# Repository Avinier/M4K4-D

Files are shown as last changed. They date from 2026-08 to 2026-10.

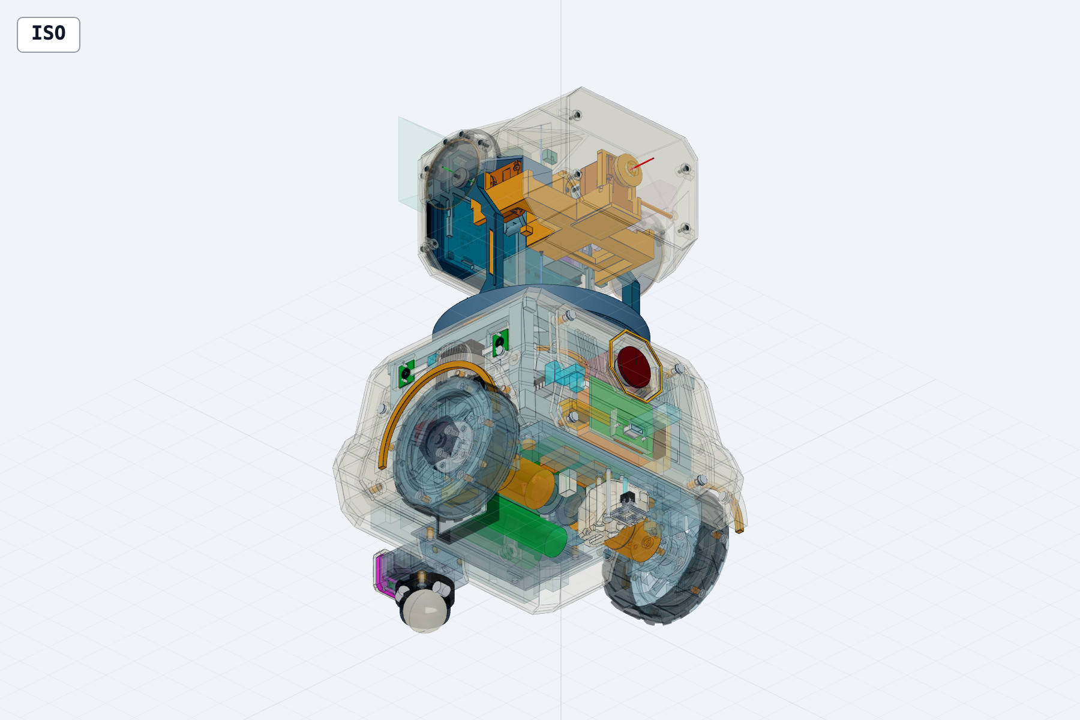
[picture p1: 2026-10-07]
docs/03-build/03-head/v1/cad/snapshots/head-v1-integrated-ear-opposite_20261005T164502Z.png

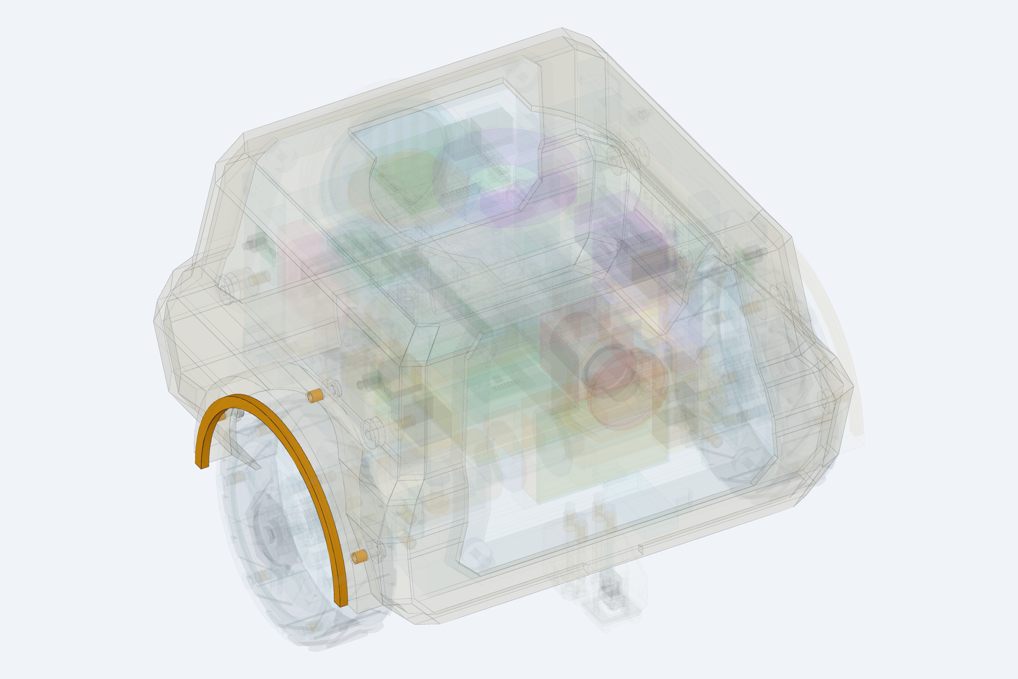
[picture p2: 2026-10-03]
docs/03-build/02-body/v1/cad/snapshots/body-v1-wheel-arch-joint-inside-2026-10-03.png

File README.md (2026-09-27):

# Makad / M4K4-D

> **Current project overview** — last reconciled **26 September 2026**
>
> Foundation approved: **14 August 2026** · V1 deadline: **5 December 2026**

**Makad**, technical designation **M4K4-D** and commonly shortened to **M4**, is a personal droid. M4 is intended to occupy the kind of companion role R2-D2 occupied for Luke Skywalker: recognizable, attentive, expressive, and full of character.

The central V1 priority is simple:

> **M4 should feel alive.**

Makad's defining advantage is expressiveness. That expression comes from what M4 understands, sees, and hears, and from how convincingly its display, status light, astromech audio, head, wheeled base, and timing communicate one intent.

`00-foundation` is the product-intent authority. Documents under `01-system` and `02-prototypes` are engineering reference. Design, sourcing, CAD, software, and hardware proceed together.

This README orients the repository around the current design, current build state, and immediate next work. [`MEMORY.md`](MEMORY.md) is a short chronological log of later consequential discoveries and decisions.

## Current design

M4 is a battery-powered floor droid with a three-axis head, an animated face, a camera-side status light, body-mounted hearing and speech, and a two-wheel base. The head carries the display, camera, status light, C2 motion controller, and local structure. The body carries four PDM microphones, the speaker, battery, and main compute. Floor mode is primary; tabletop mode inhibits locomotion by default.

The current physical target is **300 × 205 × 180 mm**. Head Layout 04 and body/chassis Layout 02 give a **293.5 mm** neutral stack (140 mm body-top datum + 49.5 mm neck + 104 mm crown-inclusive head). Drive geometry is Ø84 mm wheels, 170 mm track, 110 mm axle-to-front-support, and a mandatory rear anti-tip skid. Front support is a Ø1″ ball transfer; a swivel caster remains a comparison article on a rig, while the present CAD mount is ball-only.

Working geometry lives in [`docs/02-prototypes/RP-06-cad/`](docs/02-prototypes/RP-06-cad/README.md): head [Layout 04](docs/02-prototypes/RP-06-cad/head/layout-04/README.md) and body/chassis [Layout 02](docs/02-prototypes/RP-06-cad/body-chassis/layout-02/README.md).

### Selected components

| Item | Selection | Record |
|---|---|---|
| Face display | Waveshare ESP32-S3-LCD-4.3, **no-touch, SKU 30493** — 800×480 IPS with on-board ESP32-S3/LVGL renderer | [`display-candidate-study.md`](docs/01-system/display-candidate-study.md) |
| Head camera | Raspberry Pi Camera Module 3 **Wide**, visible-light, **SC0874** | [`camera-candidate-study.md`](docs/01-system/camera-candidate-study.md) |
| Head motion controller (C2) | Waveshare **ESP32-S3-Zero**, headerless; bench twin ESP32-S3-DevKitC-1-N8R8 | [`control-topology-options.md`](docs/01-system/control-topology-options.md) §6.3 |
| Main compute (C0) | **Raspberry Pi 5, 2 GB** with official Pi 5 Active Cooler; storage and power-entry implementation still open | [`compute-control architecture`](docs/02-prototypes/RP-02-electrical/compute-control-architecture.md) |
| Base controller (C3 prototype) | **Espressif ESP32-S3-DevKitC-1-N8**, selected over N8R8 to preserve GPIO35–37 | same, CA-03 |
| Control split | C0 owns semantic behaviour; D1 renders eyes; C2 owns head trajectory and local safety; C3 owns base loops and local hazards. Production links are differential UART; C2 relays face/light state locally | same |
| Drive topology | Two encoder wheels + **front ball transfer** + mandatory rear anti-tip skid | [`dimensional-baseline.md`](docs/01-system/dimensional-baseline.md) v1.12 |
| Head construction | PLA structure and skin (provisional beyond first head), real M2 button-heads, nine-step weathered finish | [`material-finish-mass-decision.md`](docs/02-prototypes/RP-01-head/material-finish-mass-decision.md) |
| Head layout | Serial body→yaw→pitch→roll; coaxial direct roll on a supported spindle; ears roll with the face; trapezoidal camera crown; external yaw cable loop; C2 on the rolling cradle; A0 balance target | [`head/decisions.md`](docs/02-prototypes/RP-06-cad/head/decisions.md) |

Working choices now cover XC330-M181-T yaw and XC330-M288-T pitch/roll at 5 V, a two-cell Samsung 25R pack with custom protection, Pololu #4804 as the preferred drive-motor candidate, the audio and status-light parts, and the four-board power architecture. These are not purchased or bench-frozen. Motor SKU lock, production camera interconnect, moving harness, storage, board schematics and layouts, and power/safety proof remain open.

## Current build state

The design is far ahead of the physical robot. Head and body CAD exist; electrical and locomotion behaviour are specified on paper; no integrated article has been built, weighed, or run.

| Area | State (2026-09-26) |
|---|---|
| Foundation | Approved. Some numeric thresholds remain open. |
| Geometry | Head Layout 04 is the working 1:1 model; body/chassis Layout 02 live-imports it. Neutral height is 293.5 mm. Screw collisions and sign mapping are closed in CAD; stiffness, hard-stop impact, bearing fit and balance trim await hardware. The body layout still has unresolved connector, joint and safety details. Not a fabrication release. |
| Head mechanism | Concept A (elevated-ear serial gimbal) is the path. The XC330 family is a working choice, with internal inertia bounded on paper. Nothing is weighed; actuator B1–B6 tests remain. |
| Electrical / control | States, power topology, compute split, and C0↔C2 message/recovery design are written. Host codec work is exploratory. Pack sizing still needs drive measurements. |
| Locomotion | Two-wheel + ball + skid is the V1 type. Pololu #4804 is the preferred motor candidate and its official STEP is in CAD; SKU lock, hubs, axle proof and drive tests remain. Layout 02 packages one guarded rear TCRT channel, short of the fuller stop-path sensing in the control design. |
| Interaction / following | Audio-path requirements and following architecture are documented. No SKU, corpus, or physical test. |
| Software / firmware | Timebase, link contract, C2/C3 firmware, and C0 behaviour are specified more than implemented. |
| Physical hardware | Selected display, camera, C2, Pi 5, and cooler are locked on paper. First weigh-ins wait on samples. No head, chassis, or electrical rig has been built. |

`visuals/` are provisional references; several show superseded details (mouths, ear microphones, yoke-mounted ears).

## Immediate next work

Sourcing, CAD, software, and hardware proceed together. The useful next work is:

- **Verify the current head design on hardware:** measure pitch/roll stiffness, hard-stop impact and balance trim; trial-fit the 696-2Z bearings and XC330 actuators.
- **Choose and source remaining parts** as packaging needs them — head servos, wheels/hubs/motors, ball transfer, battery and power hardware, audio, status LED, connectors — and replace CAD envelopes with real geometry.
- **Keep the whole-robot model current** in RP-06: the 293.5 mm stack is closed in CAD; reconcile Layout 02's rear-only cliff channel and low-object contact gap with the base safety design.
- **Implement firmware and software** on the same timeline: C2/C3, C0 behaviour and perception, the serial link and timebase, and face rendering on the display.
- **Build and measure** as parts arrive: weigh display, camera, C2, prints, and finish coupons; print the head and chassis; stand up a protected bench and start moving hardware.

## Documents

### Product intent — authoritative

- [Vision](docs/00-foundation/vision.md)
- [V1 scope](docs/00-foundation/v1-scope.md)
- [Constraints](docs/00-foundation/constraints.md)
- [Success criteria](docs/00-foundation/success-criteria.md)
- [Core interaction scenarios](docs/00-foundation/core-interaction-scenarios.md)

### Current engineering

- [Dimensional and packaging baseline](docs/01-system/dimensional-baseline.md)
- Working CAD: [RP-06-cad](docs/02-prototypes/RP-06-cad/README.md) — [head Layout 04](docs/02-prototypes/RP-06-cad/head/layout-04/README.md), [body/chassis Layout 02](docs/02-prototypes/RP-06-cad/body-chassis/layout-02/README.md)
- Ledgers: [mass/envelope](docs/01-system/mass-envelope-ledger.md), [power/energy/thermal](docs/01-system/power-energy-ledger.md), [candidate sourcing](docs/01-system/candidate-sourcing-matrix.md)
- Studies: [control topology](docs/01-system/control-topology-options.md), [display](docs/01-system/display-candidate-study.md), [camera](docs/01-system/camera-candidate-study.md), [head harness](docs/01-system/head-harness-routing-study.md)

### Research and history

These folders are engineering reference. They do not set how work proceeds.

- [System design brief](docs/01-system/system-design-brief.md), [risk-prototype plan](docs/01-system/risk-prototype-plan.md), [workbench](docs/01-system/workbench.md), [run-record convention](docs/01-system/run-record-convention.md)
- Head: [`RP-01-head/`](docs/02-prototypes/RP-01-head/)
- Electrical: [`RP-02-electrical/`](docs/02-prototypes/RP-02-electrical/README.md)
- Locomotion: [`RP-03-locomotion/`](docs/02-prototypes/RP-03-locomotion/README.md)
- Coordination: [`RP-04-coordination/`](docs/02-prototypes/RP-04-coordination/README.md)
- Interaction: [`RP-05-interaction/`](docs/02-prototypes/RP-05-interaction/README.md)
- Following: [`RP-07-following/`](docs/02-prototypes/RP-07-following/README.md)
- Earlier memory log: [`archive/MEMORY-20260921.md`](archive/MEMORY-20260921.md)

## Repository

```
docs/00-foundation/     product intent and constraints     authoritative
docs/01-system/         engineering reference
docs/02-prototypes/     studies, calculations, and working CAD
docs/archive/           superseded documents
archive/                prior process log
MEMORY.md               chronological build and decision log
README.md               this orientation
```

## Identity and design direction

M4 is a droid, not a desktop assistant, smart speaker, or generic social robot. The approved direction is:

- strongly inspired by Star Wars droids;
- cyberpunk, rugged, scrappy, and characterful;
- mechanical rather than glossy or appliance-like;
- modular and screw-together, with visible fasteners, panels, seams, and service access as part of the personality;
- eyes only on the face, no mouth;
- approachable without optimizing for minimum size;
- open to substantial redesign from the current renders.

## V1 Core

V1 is not complete unless the following outcomes work together as one droid. Exact wording lives in [`v1-scope.md`](docs/00-foundation/v1-scope.md) (SCOPE-01…21).

**Expression and character** — animated face on the onboard display; powered roll, pitch and yaw head motion; at least one controllable LED beside the camera; a builder-authored non-English astromech language; idle aliveness without manual control; display, LED, audio, head, base and timing express one intent; at least one bounded excited spin.

**Understanding and perception** — natural spoken interaction within the approved scenarios; invocation forms **"M4," "M4K4," and "Makad"**; visual acquisition of a nearby person or face; tracking maintained or reacquired through later-defined test cases.

**Mobility and following** — battery-powered wheeled floor droid; "come here" finds, approaches and stops at a bounded distance; "follow me" tracks the selected person through an approved indoor route; obstacles, stopping, target loss and unsafe conditions are handled without continuing blindly.

**Utility and entertainment** — display the time; create and signal timers and alarms; start Spotify playback through an approved integration; eyes "vibe" to music.

**Operation and construction** — untethered on onboard battery for at least 20 minutes; floor mode primary; tabletop mode inhibits locomotion by default and protects edges; accessible stop or cutoff with bounded failure; assembled, started, demonstrated, inspected and serviced from documentation.

**Candidate:** spatial/directional hearing, included only if it materially improves an approved interaction. Everything else is uncommitted; there is no permanent "never" list.

## Approved Core scenarios

Source: [`core-interaction-scenarios.md`](docs/00-foundation/core-interaction-scenarios.md).

**1. Wake, socialize, assist.** M4 idles head-down. A person calls its name. M4 wakes as one coordinated performance: three-axis head rise, eyes, camera-side LED, astromech acknowledgement, face acquisition and gaze. A greeting produces an in-character response. The person can request the time, a timer, an alarm, or Spotify playback; M4 confirms visibly, performs it, and vibes during music.

**2. Come here and follow me.** On an approved floor, the person invokes M4 and says "come here." M4 acknowledges, searches, acquires, turns, approaches safely and stops approximately 0.6–0.9 m away. "Follow me" makes M4 follow through an approved route of up to about 3 m at no more than about 0.5 m/s while handling obstacles and target loss. When continuing is unsafe, M4 stops and says so. M4 performs an excited spin and settles.

## Success definition

V1 succeeds when M4 delivers these interactions as a convincing, repeatable droid encounter on battery power, not as a sequence of manually rescued subsystem demos. The validation categories and open thresholds are in [`success-criteria.md`](docs/00-foundation/success-criteria.md) (SC-01…25).

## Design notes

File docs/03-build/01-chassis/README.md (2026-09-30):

# 01 — Chassis and locomotion

The [v1 BOM](v1/BOM.md) lists installed chassis quantities, references to full-system electrical parts and the separate bench-test requirements, and the open decisions that prevent release. The [project BOM](../BOM.csv) is the canonical register for sourcing and status. The [v1 CAD starting point](v1/cad/README.md) defines the current model boundary and exclusions. The [v1 test system](v1/testsystem.md) sets out receiving checks, coupons, fixtures, assembly and stress tests, and the rolling-chassis test sequence.

The v1 snapshot is a working list. Freeze it only after purchased parts are received and measured, custom parts and fasteners are specified, and the chassis checks and test criteria are complete.

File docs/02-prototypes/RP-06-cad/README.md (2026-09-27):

# RP-06 — Sourced layout CAD

| Field | Value |
|---|---|
| Status | **This folder owns the working CAD.** Phase A packaging is the article. Physical validation is 0%. No gate registered, no mock-up built, no scored run |
| Governing plan | [`risk-prototype-plan.md`](../../01-system/risk-prototype-plan.md) v1.15 §RP-06 |
| Purpose | Working whole-robot packaging for an obtainable, serviceable layout |
| Active models | Head [Layout 04](head/layout-04/README.md). Whole body [Layout 02](body-chassis/layout-02/README.md) |
| Closure instrument | [`TODO.md`](TODO.md); detail in [`checklist.md`](checklist.md) |

RP-01 is an object. RP-02 is states and interfaces. RP-03 is a vehicle plus local safety. **RP-06 is the whole-robot packaging prototype**, and therefore the home of the CAD.

RP-01 and RP-03 keep mechanism, physics, gates and rigs; they link here for geometry.

## Start here

| Document | What it owns |
|---|---|
| [TODO](TODO.md) | Builder remaining-work punch list |
| [Closure checklist](checklist.md) | Remaining G01–G06 work; CAD-done vs physical-open |
| [Head Layout 04](head/layout-04/README.md) | Active 1:1 head. Viewer, verification, mass tree |
| [Body/chassis Layout 02](body-chassis/layout-02/README.md) | Active whole-robot assembly. Live-imports Layout 04 |
| [Head decisions](head/decisions.md) | Head CAD decisions and revisions |
| [Body/chassis CAD-context decisions](decisions.md) | `RP03-CAD-01…12` (CAD-first, not RP-03 safety approval) |
| [Peripheral selection](peripheral-selection.md) | Audio path, mics, speaker/amp, status LED and base IMU working selections (2026-09-26) with evidence |
| [Prototype open items](../openitems.md) | Folder-wide remaining-open index |

## CAD map

```text
RP-06-cad/
├── head/                  Layout 04 active; 03, 02 and 01 preserved
│   ├── layout-04/         1:1 packaging, service, optics, harness overlays
│   ├── layout-02/         preserved previous head
│   ├── layout-01/         first study + purchased catalog STEP
│   ├── decisions.md
│   └── requirements.md
├── body-chassis/
│   ├── layout-02/         active whole-robot model
│   └── layout-01/         previous body; shared purchased/ STEP
├── decisions.md           body CAD-context register
├── TODO.md
└── checklist.md
```

Open Layout 04 in CAD Viewer from [`head/layout-04/README.md`](head/layout-04/README.md). Open the whole robot from [`body-chassis/layout-02/README.md`](body-chassis/layout-02/README.md). Body/chassis composes the head from live Python source — do not redraw it as an AABB.

| Head notes | Body notes |
|---|---|
| [Layout 03 brief](head/layout-03-brief.md) | [Layout 02 brief](body-chassis/layout-02/brief.md) |
| [Layout 03 verification](head/layout-03/review/verification.md) | |
| [Packaging estimates](head/packaging-estimates.md) | [Layout 01 body](body-chassis/layout-01/README.md) (preserved) |
| [Pre-layout brief](head/pre-layout-brief.md) | Purchased Pi 5 / 608ZZ STEP live locally under `body-chassis/layout-01/references/purchased/` (not in Git) |

## Locked inputs RP-06 may not reopen

| Item | Value | Home |
|---|---|---|
| Moving-head load | Layout 04's current hand-kept mass tree is about **588 g**; it is an estimate, not M900 `W`. Layout 03's 499–524 g screening range is historical. Former ~250 g target is inadmissible | [Layout 04](head/layout-04/README.md); [`dimensional-baseline.md`](../../01-system/dimensional-baseline.md) |
| Head envelope | **104 × 150 × 115 mm** crown-inclusive | same |
| Neutral stack | **293.5 mm** (140 body + 49.5 neck + 104 head, head Layout 04 turntable). Meets the 300 mm rounded target with 6.5 mm to spare; closed 2026-09-26 | same |
| Display / camera / C2 / C0 | SKU 30493; SC0874; ESP32-S3-Zero; Pi 5 2 GB + official Active Cooler | component studies; RP-02 |
| Drive topology | Two-wheel + Ø1″ ball + rear skid | baseline v1.12 |

## Owned elsewhere — link, do not copy

| Subject | Home |
|---|---|
| Dimensional / CoM targets | [`dimensional-baseline.md`](../../01-system/dimensional-baseline.md) |
| Mass ledger | [`mass-envelope-ledger.md`](../../01-system/mass-envelope-ledger.md); RP-01 [`payload-mass-capture.md`](../RP-01-head/payload-mass-capture.md) |
| Sourcing / landed cost | [`candidate-sourcing-matrix.md`](../../01-system/candidate-sourcing-matrix.md) |
| Display / camera / harness gates | display study; camera study; [`head-harness-routing-study.md`](../../01-system/head-harness-routing-study.md) |
| Head motion / actuators / scored gates | RP-01 `physics.md`, `gates.md`, `rig.md` |
| Drive physics / scored gates | RP-03 `physics.md`, `gates.md`, `rig.md` |
| Audio `AR-*` / `AP-*` | RP-05 [`audio-requirements.md`](../RP-05-interaction/audio-requirements.md) |
| Thermal trip-wire T-3 | [`power-energy-ledger.md`](../../01-system/power-energy-ledger.md) |

## What to do next

1. Keep editing **this** tree. Fit actual sourced articles into body Layout 02 and head Layout 04.
2. ~~Accept or recover the 304 mm stack~~ — closed: the neck is 49.5 mm, the stack 293.5 mm. **CoM:** [`RP03-CAD-09`](decisions.md) accepted a previous 2,568 g hand-kept register at x +18.77 / h 105.05 mm, retaining the 81.6 g [`RP03-CAD-08`](decisions.md#rp03-cad-08--ballast-bar-ahead-of-the-battery-tub) bar and adding no more. The latest `body-chassis/layout-02/generated/mass-properties.md` reads 2,551.9 g at x +19.46 / h 107.27 mm (a_tip 1.78 m/s²); the physical robot still needs weighing.
3. Do not ballast the head to 250 g.
4. Physical mock-up and G01–G06 registration wait on representative head, electrical, and acoustic evidence.

## Organization record — 2026-09-21

Builder direction: all prototype CAD from RP-01 and RP-03 moves here as `RP-06-cad`. RP-01 `cad/` and RP-03 `cad/` become forwarding stubs.

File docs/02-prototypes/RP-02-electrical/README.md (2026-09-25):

# RP-02 — Electrical/Control Backbone

| Field | Value |
|---|---|
| Status | **Parts 1–4 are complete at design-definition level.** Part 4 is `RP02-P4-REG-01` (C0↔C2) plus `RP02-P4-REG-02` (`BASE_*`) plus `RP02-P4-REG-03` (cue identity / `start_at_us` / onset reports / extra `NACK` values, 2026-09-21). Byte layouts, numeric timeouts, remaining component suffixes, purchase and scored evidence stay open. Phase A is live |
| Governing plan | `../../01-system/risk-prototype-plan.md` v1.12 §RP-02 |
| Purpose | Close **ADR-03** (controller backbone), **ADR-12** (internal communication and timebase) and the *architecture* half of **ADR-06** (battery, rails, isolation, low-energy policy); bound the *sizing* half |

RP-01 is an object. RP-02 is a set of states and interfaces: a tree of rails, four compute/control roles, message contracts across noisy and moving boundaries, and a space of concurrent operating conditions. Every subsystem will work alone; AD-08 says the peaks happen together. RP-02 is the instrument that makes the coexistence failure visible before the enclosure exists.

## Start here

| Document | What it owns | Phase live |
|---|---|---|
| [Glossary](glossary.md) | Reader index for every RP-02 namespace, registered Part-1 label, Part-2 `EDB/EC/PA/PB/PCD/BR` label, evidence/status label, protocol label and common notation | A |
| [Electrical design basis](electrical-design-basis.md) | Approved `EDB-01…08`; normalized `EDB-03` source/load contracts, composition rules, branch-boundary requirements and open dependencies | A |
| [Power branch contracts](power-branch-contracts.md) | Branch-side `EDB-03` contracts for every registered `PB-*` path, aggregation equations and calculation-readiness register | A |
| [Power implementation basis](power-implementation-basis.md) | Registered voltage-domain, return, connector, conductor, protection, capacitance and circuit-sequencing rules beneath the topology; selects Raspberry Pi 5 2 GB | A |
| [Power calculation ledger](power-calculation-ledger.md) | Derived voltage-drop, conductor/contact heat, converter-loss, source-current, `MD-01` energy and fuse-coordination calculations; final ratings remain evidence-dependent | A |
| [Power-component candidate screen](power-component-candidate-screen.md) | Manufacturer-sourced `PCD-*` converter, protection, E-stop, connector, cable and charging candidates; quantitative rejection logic and dated India sourcing snapshot; no selection or purchase | A |
| [Custom board specifications](board-specs.md) | Working (unregistered) per-board design, v0.19 (2026-09-25): parts, values, sizes and evidence lists for the four custom power/safety PCBs (pack protection, charge and system power, motor gate and head/drive distribution, branch converters) and the watchdog block; no gate registered, no SKU frozen, no purchase authorized | A |
| [Registration draft `RP02-P2-REG-04`](registration-draft-reg-04.md) | **Draft, not registered.** Proposed supersession of the `PB-COMPUTE` 5.1 V nominal, the `PA-14` `OFF` wording and the arm-latch clear rule, with the edits to make on approval and an approval block for the builder | A |
| [Brownout, reset and restart contract](brownout-restart-contract.md) | Registered `BR-*` slow-depletion/fast-collapse policy, threshold ownership, fail-inactive motor permission, reset defaults, fresh-intent recovery, sizing equations and verification contract; numeric values remain evidence-gated | A |
| [Compute/control architecture](compute-control-architecture.md) | Registered `CA-01…16`: node ownership, selected base controller class, differential links, C2 display relay, process boundaries, authority leases, watchdog hierarchy, boot/arm/update/logging and new fault obligations | A |
| [Compute/control component screen](compute-control-component-screen.md) | `CCD-*` exact selections, implementation leads, rejections, dated India sourcing snapshot and receiving tests; purchase remains separately authorized | A |
| [Operating situations](operating-situations.md) | Reader-first audited umbrella map: every situation with its `OM/EN/BS/PC/AL/HL/EV`, loads, cases, faults and evidence | A |
| [Intent](intent.md) | The design question and the gate question, kept separate; traceability; inherited inputs; non-goals; the phase ladder | A |
| [State register](state-register.md) | Orthogonal mode, energy, behaviour, person-continuity, action-lifecycle and health dimensions; events, qualification cases, forbidden concurrency and `MD-01` | A |
| [State coverage matrix](state-coverage-matrix.md) | Requirement → runtime vector → qualification case → load profiles → rules/faults → evidence | A |
| [Load model](load-model.md) | Named per-load profiles, time-scale classes, aggregation rules and measurement dependencies; contains no competing numeric budget | A |
| [Power architecture](power-architecture.md) | Registered Part-2 domain/rail baseline: safety, application, motor and charge paths; independent C2/base safety branches; return topology; power-state matrix; registered `PB-*` keys | A |
| [Link contract](link-contract.md) | Registered Part-4 C0↔C2 definition (`RP02-P4-REG-01`), C0↔C3 `BASE_*` (`RP02-P4-REG-02`), coordination fields (`RP02-P4-REG-03`). Byte layouts, type numbers, baud and measured timeouts remain open | A |
| [Phase A reference](phase-a/README.md) | Exploratory single-schema C0/C2 frame codecs, host safety/time model, board-role reservations and logging record; not scored or flashed | A |
| [Candidate circuits and paper review](phase-a/candidate-circuits-review.md) | Candidate compute/C2/display, E-stop and link circuits plus unscored G01/G06 walk | A |
| [Fault matrix](fault-matrix.md) | `F-01…F-30` injected faults × inhibit / reject / expose / recover, including Part-3 process, watchdog, relay, differential-link, storage and reset cases | A (rows), B (campaign) |
| [Rig](rig.md) | The distribution bench: fuses, INA-class monitors, E-stop, real-versus-substitute loads with equivalence records, procedures | A (design), B (build) |
| [Gates](gates.md) | Candidate registrations for G01/G04/G05/G06; what RP-02 records against the reshaped G02 invariant and the G03/SC-14 rehearsal | A (registration) |
| [Decision](decision.md) | Gate outcomes, the **ADR closure ladder** (ADR-06 split into architecture and sizing), selected Pi 5 record and remaining candidate register | — |
| [Prototype open items](../openitems.md) | Folder-wide remaining-open index; ratings, SKUs and gates stay in their owning files | — |
| `runs/` | Run records per `../../01-system/run-record-convention.md` | — |

## Owned elsewhere — link, do not copy

| Subject | Home | Why it is not here |
|---|---|---|
| **Power / energy / thermal budget** | [`power-energy-ledger.md`](../../01-system/power-energy-ledger.md) | Serves every prototype that energizes anything. Two budgets means one is wrong. RP-02 *populates* it |
| **Monotonic timebase** | [`timebase.md`](../../01-system/timebase.md) | A continuous-workstream deliverable; RP-01's first scored run needs it too. RP-02 *validates* it under G05 |
| System control-topology study | [`control-topology-options.md`](../../01-system/control-topology-options.md) v0.14 | Part 3 consumes and closes its ownership/link choices at design level; physical evidence still closes ADR-03/ADR-12 |
| Bench tools, PSU and E-stop rules, battery gate | [`workbench.md`](../../01-system/workbench.md) | Programme-wide |
| Candidate parts and cost range | [`candidate-sourcing-matrix.md`](../../01-system/candidate-sourcing-matrix.md) | Programme-wide |
| Head harness partition and yaw boundary | [`head-harness-routing-study.md`](../../01-system/head-harness-routing-study.md) | Shared with RP-01 |
| Run identity | [`run-record-convention.md`](../../01-system/run-record-convention.md) | Programme-wide |

## Why the gates changed shape (plan v1.10)

G01, G04, G05 and G06 are properties — a fuse coordinates or it does not; a stale command is rejected or executed. They stay as pass/fail gates. G02 (peak coexistence) and G03 (runtime) are budgets: they need hardware that does not exist at stage 2, they reopen every time a subsystem arrives, and G03 duplicates SC-14. So G02 became a **standing invariant with a re-run rule** owned by the ledger, and G03 became an **early-warning rehearsal with recorded margin**, with the 20-minute requirement closing where it already lives — SC-14 at integration. The reasoning is in `intent.md` §2 and the amendment in the plan's approval note.

## Relationship to RP-01

Circular, and named — but the two closures are different objects. RP-01's **complete-head `W` mass** (M900) cannot close while M008 is `U`; that is unchanged. Layout 03 **paper demand** does not wait on that weigh-in: it is complete as of 2026-09-13 (`fullproofmath.md`), using the 20 g `E` C2 case plus 10/20/35 g sensitivity. C2's timing and electrical validity is still RP02-G05; RP-01's first scored run still needs RP-02's timebase. The servo **family** is still unselected and still sets the servo rail, but RP-01 now has a named paper candidate — XC330-M288-T (C01), proposed 5 V, paper approval OPEN — which is a leading PA-04 working assumption, not a collapse. Resolution: RP-02 Phase A runs now and unblocks RP-01; Phase B may use C01 as a named reference load without treating a purchase as a family freeze; load-dependent gates that need the frozen rail follow selection.

## What to do next, in order

1. Implement the C0/C2 shared schema, board-role pin maps and authority-lease state machines from the registered Part-4 definition, including `RP02-P4-REG-03` cue identity / `start_at_us` / `FACE_REPORT` / `LIGHT_REPORT` / extra `NACK` values. C3 `BASE_*` **semantics** are registered (`RP02-P4-REG-02`); byte layouts and the candidate TTL/heartbeat/queue numbers stay unregistered until Phase A measures them. The C3 board-role header is `phase-a/c3_board_role.h`. No hardware purchase is required for codec/unit simulation.
2. Implement `timebase.md` and `link-contract.md` v0.6 on the DevKitC-1 twin, first TTL loopback and then THVD1451 differential breakout pairs; exploratory timing runs do not wait on carrier PCBs.
3. Freeze the first executable case configurations and register G05/G04 numeric thresholds before scored link/watchdog work, including `F-23…30`.
4. Convert the surviving `PCD-*`/`CCD-*` leads into reviewed candidate circuits and bench configurations; choose exact transceiver/watchdog suffixes only from the measured timing and harness conditions.
5. Build the distribution/link rig when the required instruments arrive and run G01 review plus differential-link/watchdog pilot injections.
6. After RP-01 selects a servo family, collapse PA-04/servo transceiver and begin scored Phase B. RP-03 supplies the motor-driver/sensor pin freeze and representative drive load; C01 remains a reference, not a freeze.

## Organization record — 2026-09-08

Created by builder direction after the RP-01 head reached its first packaging study and the C2 module was selected. The folder deliberately does not mirror `RP-01-head/`: there is no `physics.md` (the ledger is the model), no `storyboard.md` (the state register is its analogue), no `concepts/` or `cad/`. The power/energy ledger and timebase strategy were placed in `01-system/` under the same rule that kept the RP-01 CAD folder's sources in place — documents serving more than one consumer stay put and get linked.

Reconciled 2026-09-13 to RP-01 Layout 03 paper demand and C01 (XC330-M288-T) without selecting a servo family or collapsing PA-04.

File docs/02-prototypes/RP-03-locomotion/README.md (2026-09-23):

# RP-03 — Drive and Local Motion-Safety Rig

| Field | Value |
|---|---|
| Status | **Parts 1–5 remain complete at design-definition level.** `RP03-P1-REG-01` … `RP03-P5-REG-01` (2026-09-17). Brief-gap close 2026-09-18 issued `RP03-P1-REG-02` … `RP03-P4-REG-02` (operating cases, remaining physics, complete drive sets, TTL/cutoff/`CA-14` header). Numeric thresholds, candidate freeze, purchase and scored evidence stay open. Phase A is live on paper; scored runs wait on the workbench gate, timebase, and this rig |
| Governing plan | `../../01-system/risk-prototype-plan.md` v1.12 §RP-03; folder construction record [`plan.md`](plan.md) |
| Purpose | Close **ADR-04** (wheeled-drive and passive-support geometry) and **ADR-07** (obstacle and tabletop-edge sensing) *provisionally*; supply the drive `W` rows that ADR-06 sizing waits on; freeze the C3 pin map, motor-driver/sensor interface and base message set that RP-02 left open; deliver the measured base model RP-04 composes against |

RP-01 is an object. RP-02 is a set of states and interfaces. **RP-03 is a vehicle plus a safety authority.** It is the first prototype that can destroy itself (a desk edge), the first with real inductive and regenerative load on the motor bus, and the first with a sensor inside the stop path.

## Start here

| Document | What it owns | Phase live |
|---|---|---|
| [Intent](intent.md) | Why RP-03 exists; the two questions kept separate; ADR table; inherited inputs; `BM-00…BM-14` character read; `FS-*`; non-goals; phase ladder; evidence rules | A |
| [Storyboard](storyboard.md) | Authored panels `BM-00…BM-14`; operating-case grammar; `FS-01…11`; wheel-velocity profile library; kinematic export | A |
| [Physics](physics.md) | `a_tip` as a **range**; four loading cases; head-pose CoM; slope 2.0°; heat; low-voltage; flutter; support triangle; CON-TBD-14 *proposal* | A |
| [Concepts](concepts/README.md) | Two competing concepts and the filled comparison. **Selected installed path: Concept A chassis/sensing + `D21` ball (BD-08). Not a gate freeze.** `D20` is the required swap | A |
| [Drivetrain screen](drivetrain-screen-01.md) | Complete **Set A / Set B**; `D01…` class rows; paper P01–P09 vs the sets. **Set A / D02 is a reference-unit lead, not a freeze** | A |
| [Sensing screen](sensing-screen-01.md) | `S01…` cliff/obstacle/bump/IMU; coverage/latency/C3 I/O. **S01/S04/S06/S07 are leads, not a freeze** | A |
| [Base control](base-control-architecture.md) | `BC-01…BC-10`; C3 pin map v0.1 (≥2 spare safe GPIO); `BASE_*` draft; candidate TTL | A |
| [Fault matrix](fault-matrix.md) | `F-31…F-45` plus cross-listed `F-19/F-22/F-26`; campaign order bench → floor → tabletop last | A (rows), B/C (campaign) |
| [Rig](rig.md) | Ugly chassis, ballast CoM, sensor interposer, catch fixture, course, readiness checklist | A (design), B (build) |
| [Gates](gates.md) | Paper `RP03-P01…P09` scored against the sets (OPEN); physical candidate `RP03-G01…G06` including cutoff-coast; **registered section empty** | A (candidate) |
| [Decision](decision.md) | Inherited locks; `BD-01…07` paper-confirmed 2026-09-18; **`BD-08` selects `D21` (2026-09-19, baseline v1.12)**; Part registrations; ADR ladder; candidate register | — |
| [Research](research.md) | Constraints, inventory, filled envelopes, print-vs-buy. CAD datums §5. Not a sourcing matrix, not a freeze, not a purchase | A |
| [Folder plan](plan.md) | Construction record: layout, Part order, what each file may not contain | Retired into this README's organization record; file kept |
| [Prototype open items](../openitems.md) | Folder-wide remaining-open index | — |
| [CAD](../RP-06-cad/README.md) | Working body/chassis/head geometry moved to RP-06. | — |
| `runs/` | Run records per [`run-record-convention.md`](../../01-system/run-record-convention.md) | — |

Namespaces (no glossary): `BM-` panels · `D` drivetrain · `S` sensing · `BC-` base-control rules · `F-3x` faults · `BD-` builder decisions · `RP03-P` paper gates · `RP03-G` physical gates · `RP03-P<n>-REG-<nn>` Part records.

## Owned elsewhere — link, do not copy

| Subject | Home | Why it is not here |
|---|---|---|
| Drive geometry targets | [`dimensional-baseline.md`](../../01-system/dimensional-baseline.md) | Programme-wide; RP-03 measures, does not re-derive |
| Drive / battery mass rows | [`mass-envelope-ledger.md`](../../01-system/mass-envelope-ledger.md) | RP-03 populates the drive row; physics did not move 200–600 g |
| `LG-04` / `LG-10` and G02 invariant | [`power-energy-ledger.md`](../../01-system/power-energy-ledger.md) | Two budgets means one is wrong |
| `OM/BS/EV/CC/LP`, `MD-01` | RP-02 [`state-register.md`](../RP-02-electrical/state-register.md), [`load-model.md`](../RP-02-electrical/load-model.md) | RP-03 extends; it does not fork |
| C0↔MCU framing, expiry, heartbeat, arm nonce | RP-02 [`link-contract.md`](../RP-02-electrical/link-contract.md) v0.4 C0↔C2 (`RP02-P4-REG-01`); v0.5 C0↔C3 **semantics** (`RP02-P4-REG-02`). Byte layouts stay open | Envelope lives there; payloads are defined here |
| `PA-13` motor authority, `PB-DRIVE*` | RP-02 [`power-architecture.md`](../RP-02-electrical/power-architecture.md) | Keys registered; drive `W` is RP-03's |
| `F-19` / `F-22` / `F-26` | RP-02 [`fault-matrix.md`](../RP-02-electrical/fault-matrix.md) | Cross-listed here, not renumbered |
| C3 I/O budget and `CA-*` | RP-02 [`compute-control-architecture.md`](../RP-02-electrical/compute-control-architecture.md) | Pin map v0.1 is the RP-03 fill of that budget |
| Sourcing rows | [`candidate-sourcing-matrix.md`](../../01-system/candidate-sourcing-matrix.md) §Drive & base | Programme-wide |
| Bench, PSU, E-stop, battery gate | [`workbench.md`](../../01-system/workbench.md) | Programme-wide |
| Run identity | [`run-record-convention.md`](../../01-system/run-record-convention.md) | Programme-wide |
| Timebase | [`timebase.md`](../../01-system/timebase.md) | Scored G01–G06 need it implemented |

## The finding that must not become a target

`a_tip ≈ 2.0 m/s²` is a **placement target** at `x_CoM = +25 mm`, `h_CoM = 124 mm`. A lumped Layout 03 model does not hit it: `a_tip` lands about **0.9–1.9 m/s²** if the battery stays low and forward, and **changes sign** if the battery sits on or behind the axle. Storyboard `a_peak` 0.80–1.00 m/s² only has margin when ballast restores `x_CoM ≥ +20 mm`. If the target is missed, the dimensional baseline is revised — commanded acceleration is not quietly shrunk to hide it. Detail: [`physics.md`](physics.md) §2.

## What to do next, in order

1. Do not buy. Set A / `D02` / **`D21` ball (type selected, SKU open)** / `DRV-B` / `S01` / `S04` / `S06` / `S07` are leads. A reference motor or ball transfer on the bench is equipment until a freeze says otherwise. Catalog gaps: **print hubs/shims/two adapters**; **import** the encoder motor; **buy** the Ø80–85 tread and the 1″ POM ball (`research.md` §1.5).
2. Working CAD is in [`RP-06-cad/`](../RP-06-cad/README.md). Those models are working articles, not a gate freeze or frozen SKU solids — selected path remains unfrozen.
3. When a driver evaluation board and one reference motor are on the bench: Phase A C3 loop-rate, encoder capture and watchdog feed. Exploratory. Not a scored RP-03 run. Implement `timebase.md`.
4. Freeze G01–G06 numeric thresholds **before** inspecting scored data. Build the ugly chassis. Then Phase B on the floor, Phase C caught-tabletop last. The 240 fps acted mock-up in `plan.md` is still open.

Paper brief-gaps (operating cases, BD confirmation, remaining physics, TTL/cutoff/`CA-14`, complete drive sets) closed 2026-09-18 under `RP03-P1-REG-02` … `RP03-P4-REG-02`.

## Organization record — 2026-09-17

Created by builder direction after RP-01 Layout 03 paper demand and RP-02 Parts 1–4 were defined. The folder follows the RP-02 pattern (Part registrations, evidence classes, thresholds freeze before data) because RP-03's two closures are different kinds of object: ADR-04 closes into *geometry*, ADR-07 into *architecture*. Mixing them is how a chassis quietly chooses the sensors.

`plan.md` is the construction record. Parts 1–5 are now populated at design-definition level. This README is the start-here index; it is not canonical for any number, SKU, pin or threshold.

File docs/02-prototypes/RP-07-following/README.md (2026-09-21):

# RP-07 — Person tracking and short household following

| Field | Value |
|---|---|
| Status | **Documentation baseline complete 2026-09-21. Paper architecture and test programme only. No camera recording, implementation, physical motion, scored run, gate pass, or ADR closure.** |
| Governing plan | `../../01-system/risk-prototype-plan.md` §RP-07 |
| Primary decision | ADR-09 — person acquisition, continuity, localization, and following architecture |
| Depends on | Approved foundation; selected camera/system records; RP-01 head; RP-02 states/time/power; RP-03 base and local safety; RP-04 coordination |

RP-07 asks whether Makad can acquire, select, retain, lose, reacquire, approach, and follow one person inside the approved single-room envelope without moving on stale or ambiguous evidence.

This folder is intentionally a **complete paper prototype**. It specifies the implementation and evidence required later. It does not fabricate camera recordings, human-subject trials, motor tests, timings, thermal results, or safety outcomes.

## Start here

| Document | Owns |
|---|---|
| [Intent](intent.md) | Decision question, scope, completion boundary |
| [Inherited](inherited.md) | Exact upstream contracts; conflicts and precedence |
| [Requirements](requirements.md) | RP-07-owned perception, continuity, geometry, compute and control requirements |
| [Decision](decision.md) | Paper selections, open decisions, registration ladder |
| [Perception architecture](perception-architecture.md) | Capture, detection, tracking, appearance, face evidence, publication |
| [Interfaces](interfaces.md) | Typed observation, selection, goal, and feedback contracts |
| [Geometry and calibration](geometry-calibration.md) | Intrinsics, transforms, timestamps, bearing/range, uncertainty |
| [Target continuity](target-continuity.md) | Candidate/selection/loss/reacquisition and no-silent-switch policy |
| [Behaviour control](behaviour-control.md) | Search, head/base handoff, come, follow, braking, settling |
| [Safety and faults](safety-fault-matrix.md) | Authority order, stale/frozen evidence, injected failures |
| [Timing and compute](timing-compute.md) | Pi 5 workload, rates, latency, memory, thermal and fallback ladder |
| [Test matrix](test-matrix.md) | Recorded replay, live-no-motion, head-only, floor, distractor and fault cases |
| [Gates](gates.md) | RP07-G01…G07 candidate registration sheets and evidence rules |
| [Plan](plan.md) | Documentation-to-evidence execution sequence |
| [Evidence index](evidence/README.md) | Future run layout; presently empty by design |

Namespaces: `RP07-P*` paper registrations · `PS-*` perception stacks · `TM-*` target modes · `RC-*` range cues · `FC-*` following-control policies · `T07-*` tests · `F07-*` faults · `RP07-G*` gates.

## Paper conclusion

The implementation lead is `PS-HYBRID-01`:

1. Picamera2/libcamera acquisition from the locked Camera Module 3 Wide;
2. whole-person detection at a measured active cadence;
3. detection-based multi-person association;
4. an explicitly pinned selected-target identity owned by `makad-core`;
5. lightweight selected-target updates/prediction between detector refreshes;
6. appearance evidence used principally for selection and reacquisition, not biometric identity;
7. face/landmark evidence used for social gaze when available, never as the only long-range person evidence;
8. calibrated camera/head/body transforms and coarse, uncertainty-bearing range;
9. semantic, expiring come/follow goals from C0; C3 retains wheel and local-safety authority.

The lead is accepted for implementation comparison, not validated. The detector, tracker, appearance model, inference resolution, and exact rates remain benchmark selections.

## Hard boundaries

- Perception never commands motors.
- A candidate is not a selected person.
- A tracker ID is not durable human identity.
- Appearance matching is short-session continuity, not named or biometric recognition.
- Coarse visual range is never collision-safety distance.
- Loss or ambiguity brakes first; identity may be remembered while motion is stopped.
- Clearing an obstacle, link, or perception fault never resumes old motion.
- Tabletop mode rejects ordinary come and follow.
- RP-07 does not pass until representative physical evidence exists.

## Work that remains physical

The following are specified here but deliberately unperformed: camera calibration; recording the validation corpus; Pi 5 benchmarking; head-motion timing alignment; rolling-shutter characterization; live tracking; guarded base motion; come/follow trials; obstacle and cliff conflicts; injected faults; joined external video; and scored RP07-G01…G07 campaigns.

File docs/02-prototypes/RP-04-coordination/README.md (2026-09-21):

# RP-04 — Coordinated Performance Architecture

| Field | Value |
|---|---|
| Status | **Phase A design-definition 2026-09-21.** `RP04-P1-REG-01`…`P6-REG-01`. Virtual composer **`CS-HYBRID`** with bounded waits. P-02 cue list validated. Observer **draft, not frozen**. `BD-08` open. No physical gate. ADR-05 open. **Blocked on Phase B/C.** |
| Governing plan | `../../01-system/risk-prototype-plan.md` §RP-04; [`plan.md`](plan.md) |
| Purpose | Close **ADR-05** provisionally after measured G01–G05. Phase A only selects the virtual trigger adapter |

RP-01 is an object. RP-02 is states, links, and firmware/process boundaries. RP-03 is a vehicle plus local safety. **RP-04 is the first predominantly software-architecture prototype.**

## Start here

| Document | What it owns | Phase |
|---|---|---|
| [Intent](intent.md) | Why; C0/C2/C3/D1; two questions | A registered |
| [Situations](situations.md) | Catalogue + P-01 §11 + P-02 §12 cue list | A registered; P-02 paper |
| [Interface requirements](interface-requirements.md) | **Accepted** as RP-02 semantics (`RP02-P4-REG-03`); exploratory packed layout rev 2 | Request closed; codec host-only |
| [Observer protocol](observer-protocol.md) | G03 questions. Real clips only | **Not frozen** |
| [Research](research/README.md) | Family closed (`CS-HYBRID`); remaining = physical `TR-*` | Virtual software closed |
| [Runtime](runtime-architecture.md) | Shared layer; HYBRID trigger + wait language | A |
| [Timing budgets](timing-budgets.md) | `E` split: `T-LEAD` / `T-BEAT` / `T-DEAD` | Not G01 |
| [Prototype](prototype/README.md) | Virtual P-01; HYBRID waits; P-02 validator | A |
| [Gates](gates.md) | Candidates only | Open |
| [Decision](decision.md) | `BD-*`, registrations, `CS-HYBRID` | — |
| [Plan](plan.md) | Construction record | — |
| [Open items](../openitems.md) | Remaining index | — |

Namespaces: `P-0x` · `OX-*` · `CS-TIME/PROG/HYBRID` · `IR-*` · `BD-*` · `RP04-P/G` · `T-P01-*`.

## Controllers

`C0` Pi · `C2` head+safety · `C3` base+safety · `D1` face. No `C1`. Audio on C0 as a scored channel.

## What to do next

1. Phase B when the RP-01 head, D1, timebase, and audio stand-in exist. Engineering-tune on non-scored runs; freeze G03; then scored clips. Physical `TR-P01-*` are not closed by the virtual suite.
2. Close `BD-08` before implementing counter-yaw. Do not execute P-02 until the RP-03 base model exists.
3. RP-02 G04/G05 still own registering the packed layout (exploratory revision 2 is a host reference).

Do not delete `prototype` TIME/PROG adapters (`EXPERIMENTAL.md`). Do not treat virtual onsets as G01 `W`. Do not reopen UART/COBS unless measured G05 shows both 921 600 and 460 800 fail. Do not claim RP-04 or ADR-05 closed.

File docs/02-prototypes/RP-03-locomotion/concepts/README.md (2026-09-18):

# RP-03 Concepts — Comparison Matrix

| Field | Value |
|---|---|
| Status | **Paper comparison v0.1. Selected installed path: Concept A chassis/sensing + `D21` ball (BD-08). Not a gate freeze, not a purchase.** Concept B retained. `D20` caster is the required comparison swap |
| Created | 2026-09-17 |
| Owner | Project builder |
| Governing plan | `../plan.md` Part 3; `../intent.md` ADR-04 / ADR-07 split |
| Consumes | `../physics.md` (ranges, not a point `a_tip`); `../storyboard.md` `BM-00…BM-12`; `../../01-system/dimensional-baseline.md` v1.10 |
| Feeds | `../drivetrain-screen-01.md`; `../sensing-screen-01.md`; later `../rig.md` (interchangeable front support) |
| Does not claim | A winner freeze; a motor / sensor / caster SKU; a measured CoM; a pass against `2.0 m/s²`; CAD |

Two concepts are authored because `physics.md` made four first-order axes comparable. A concept without a filled comparison row is a sketch, not a concept. Naming a working lead after the table is filled is a packaging/sensing *direction for the rig*, not ADR-04/ADR-07 closure and not a purchase authorization.

Full notes: [`swivel-caster-three-lookdown.md`](swivel-caster-three-lookdown.md) (Concept A); [`ball-transfer-perimeter-cliff.md`](ball-transfer-perimeter-cliff.md) (Concept B).

## 1. Evidence and credibility

### 1.1 Grades

| Grade | Meaning here |
|---|---|
| `W` | Measured on a recorded article. **This folder contains none.** |
| `D` | Manufacturer or published-standard value applied to a named article |
| `E` | Engineering estimate, napkin geometry, or calculation from `D`/`E` inputs. Never present as measured |
| `U` | Unknown. Never silently zero |

Rules carried from `physics.md` §1.1 and RP-01/RP-02 screens: never collapse the `a_tip` range to the placement-target `1.98 m/s²`; never treat a working lead as a freeze; never put a stop-path sensor behind I2C-only or a GPIO expander.

### 1.2 Credibility checklist (both concepts must clear)

A concept is credible only when every row below is present in its file. Missing a row is a sketch.

| Check | What it must show |
|---|---|
| Napkin geometry | Ø84 wheels, 170 mm track, 110 mm wheelbase to **front-support ground contact**, 70 mm skid reach as the inherited *starting* numbers; skid reach/height remain adjustable 60–80 / 8–16 mm. No CAD |
| Load path | Where floor load goes (drive patches, front support, rear skid) under the four `physics.md` §2.6 cases. Rear skid is mandatory. HIGH_AFT battery is not a concept |
| Actuator class | JGA25-class (or a named comparison class) with a sourcing path. **Class, not a SKU freeze** |
| Cable route to body | Drive, encoder, sensor and E-stop/enable harness **up through the neck void**, demate at the body. No slip ring. No motor current through a servo-style daisy chain |
| Service story | How a motor, wheel, front support, skid pad, cliff channel and body demate come apart without destroying the CoM ballast setup |
| Physics quantities with margin | Screened against the `a_tip` **range**, the §6 stopping table, wheel torque `0.036–0.110 N·m`, encoder creep, and current class — not against `2.0 m/s²` |

### 1.3 First-order axes they must differ on

These are the axes `physics.md` §10 made comparable. Cosmetic differences do not count.

| # | Axis | Concept A | Concept B |
|---|---|---|---|
| 1 | Front support (`BM-07` trail / scrub) | Swivel caster with trail (`U` until a part is on the bench) | Ø1 inch ball transfer; no trail |
| 2 | Motor / battery vs 110 mm wheelbase (CoM lever) | Motors coaxial with the drive axle (`x = 0`); battery bay **low and forward of the axle** | Motors hung **into** the wheelbase (motor CoM `x > 0`); battery as a low floor tray around the ball well, still **forward of the axle**. HIGH_AFT is forbidden in both |
| 3 | Cliff count / placement | **Three** look-down channels: caster-forward + reverse/skid + one lateral | **Perimeter ring (4+)** look-downs around the stance |
| 4 | Obstacle stop-path class | Analog-IR (GP2Y-class ADC) **in the stop path** | ToF **as telemetry only**. Stop-path obstacle is bump GPIO. Stop-path never behind I2C-only or an expander |

Battery **must** be able to sit low and forward of the axle in both concepts. A behind-axle pack is the HIGH_AFT packaging fault (`physics.md` §2.2): `a_tip` goes negative. It is not an option in either column.

## 2. Comparison matrix

Screen against `physics.md` ranges. `a_peak = 0.80 / 1.00 m/s²` (`storyboard.md` `BM-07`/`BM-08`) has envelope margin only when `x_CoM` is restored toward the placement target. HIGH lumped `a_tip = 0.905 m/s²` has **no margin** at `0.80 m/s²`. Neither concept is allowed to hide that by shrinking commanded acceleration.

Scan line (two rows, thirteen columns). Detail follows in the criterion table so cells stay evidence-bearing rather than slogan-sized.

| | Support type | Motor placement | Battery bay | Cliff count/placement | Obstacle class | BM-07 trail | a_tip recovery | d_stop coverage at 0.50 | reverse cliff | C3 GPIO | Mass vs 200–600 | Service | Verdict |
|---|---|---|---|---|---|---|---|---|---|---|---|---|---|
| **A** | Ø25–32 swivel at +110 | JGA25-class coaxial with axle, `x ≈ 0` | Low + forward, `x = +50…+80`, `h = 18–32`. HIGH_AFT excluded | **3**: caster + skid + one lateral | Analog-IR ADC **in stop path** (GP2Y-class) | Trail `U`; one-cycle heading glitch expected | Battery-forward lever (LOW_FWD 1.90 m/s² `E`). Range, not 2.0 | **PASS** if caster-mounted (179 ≤ 300 mm `D`) | Dedicated skid look-down | 3 cliff + analog + bump + SPI/INT + 2 nFAULT + enable; ≥2 spare | 350–500 g `E`, inside | Outboard motors; caster drops; neck demate | **Working lead** (after this table). Not a freeze |
| **B** | Ø1" ball transfer at +110 | JGA25-class hung **into** WB, motor CoM `x ≈ +20…+35` | Low U-tray around cup, `x = +60…+85`. HIGH_AFT excluded | **4+** perimeter ring | ToF **telemetry only**; bump is stop-path | No trail; drag / dent / pile instead | Same battery rule + small motor +`x`. Do not claim a win | **FAIL/HOLD** as G03: bump has no 179 mm look-ahead | Ring includes rear by construction | 4+ cliff spends the spare; no expander | Upper half of 200–600 g `E` (cup+ring+coupling) | Cup clean; coupling joint; neck demate | **Comparison retained; not waived** |

| Criterion | Concept A — swivel caster, three look-downs, analog-IR stop-path | Concept B — ball transfer, perimeter cliff, ToF telemetry |
|---|---|---|
| **Support type** | Ø25–32 mm swivel caster at `+110 mm`. Trail `U`. Contact patch moves as it yaws; instantaneous `L` is not a frozen 110 mm during reverse | Ø1 inch ball transfer at `+110 mm`. Contact stays put. Higher rolling resistance `E`. Can dent soft floors / pile |
| **Motor placement** | Two JGA25-class gearmotors coaxial with the drive axle, outboard, `x ≈ 0`, `h ≈ 42 mm` (axle height). Drive mass does **not** recover `x_CoM` | Two JGA25-class gearmotors hung **into** the 110 mm wheelbase (motor CoM `x ≈ +20…+35 mm` `E`). Drive mass **does** contribute a small +`x` lever. Track still 170 mm; wheels still on the axle via belt/shaft/`E` coupling — coupling is a cost, not a freeze |
| **Battery bay** | Low bay **between axle and caster**, pack CoM `x = +50…+80 mm`, `h = 18–32 mm` `E`. This is the recovery lever (`physics.md` §2.4). HIGH_AFT excluded by construction | Low **U-tray around the ball well**, pack CoM `x = +60…+85 mm`, `h = 18–32 mm` `E`. Still forward of the axle. HIGH_AFT excluded by construction. Tray fights the ball cup for the same floor real-estate |
| **Cliff count / placement** | **3** look-downs: (1) caster-forward, (2) reverse / skid, (3) one wheel-adjacent lateral. Matches `physics.md` §7.5 minimum | **4+** perimeter ring (caster, both shoulders, skid as a starting count). Better heading coverage on paper; spends GPIO and harness |
| **Obstacle class** | GP2Y-class analog IR **in the stop path** on a C3 ADC, mounted at the caster. Triangulation, less colour-sensitive than TCRT. Bumper is last layer | VL53-class ToF **telemetry / redundant look-ahead only** (I2C). Stop-path obstacle is the GPIO bumper. Physics §7.4: do not close G03 with bump-only at follow speed |
| **BM-07 trail** | Trail makes the caster yaw on reversal; **one-cycle heading glitch is expected** (`physics.md` §3.4). Heading change > 5° per cycle is a storyboard never. Trail `U` until measured | **No trail, no swivel glitch.** Higher rolling drag on every `WIGGLE` half-cycle; ball can walk a pile or dent laminate. Different `BM-07` failure, not a free win |
| **`a_tip` recovery** | Recovers by sliding the battery bay forward and down (LOW_FWD `a_tip = 1.896 m/s²` `E`). Motors at `x = 0` do not help `x`. Lumped LOW/NOM/HIGH without that bay are `1.115 / 1.226 / 0.905 m/s²` — **not** `1.98`. Skid `14 mm @ 70 mm` still fails or is marginal until ballast restores `x`. Rig: independent `x`/`h`, skid 60–80 / 8–16 mm | Recovers by the same battery rule **plus** a small motor-mass +`x` lever. Paper `a_tip` can sit slightly above A's equivalent lumped case `E`, still a range, still not `2.0 m/s²`. HIGH_AFT remains forbidden. Coupling/shaft mass and ball-cup height can push `h_CoM` the wrong way — do not claim a better `a_tip` until the rig measures |
| **`d_stop` coverage at 0.50** | Caster-mounted analog IR: look-ahead from **caster contact** must be ≥ **179 mm** (`physics.md` §6.2). GP2Y-class max 300 mm `D` covers 179 mm with paper room. Axle-mounted would need 179+110 = 289 mm — this concept does **not** credit that | ToF telemetry can *see* past 179 mm, but it is **not** the stop path. Bumper span of the stance does not provide 179 mm look-ahead. **Coverage at 0.50 is a G03 hole** unless an analog-IR stop-path channel is added — which would collapse axis 4 and make B a variant of A, not a competing concept |
| **Reverse cliff** | Dedicated look-down covering the skid (70 mm behind axle). `BM-08` reverse launch loads the caster; reverse *creep toward an edge* is the skid-leading case. Forward-only cliff does not see it | Perimeter ring includes a rear channel by construction. Count is the advantage; dark/glossy failure mode is unchanged |
| **C3 GPIO** | 3 cliff GPIO + 1 analog obst + 1 bump + IMU SPI+INT + 2× nFAULT + fail-safe enable. Fits the planned Part 4 map with ≥ 2 spare GPIO (`compute-control-architecture.md` CA budget). No expander in the stop path | 4+ cliff GPIO **plus** bump, IMU SPI+INT, 2× nFAULT, enable. Ring spends the spare. Adding ToF I2C is bus-only and is allowed as telemetry; it does not buy back GPIO. Risk: the map fails the ≥ 2 spare rule and forces a WROOM carrier — a Part 4 change, not a silent expander |
| **Mass vs 200–600 g** | Two JGA25-class motors ~170–220 g `D`/`E` + Ø84 wheels + caster + skid + brackets → **350–500 g `E`**, inside the ledger row. Physics does not move the bound | Same motor class, **plus** ball cup / transfer, perimeter sensor brackets, and (if used) axle coupling. Likely **upper half of 200–600 g `E`**, still required to fit. A 37D-class swap would eat the row in either concept |
| **Service** | Caster fork drops down; three cliff pigtails; motors outboard on the axle; neck-void harness demates at the body. Skid pad is a screw-adjust shim. Ballast bays independent of the caster swap | Ball cup contamination (hair, grit) is a scheduled clean. Perimeter ring is more connectors. Motor-in-WB coupling is an extra service joint. Neck demate identical. Interchangeable front support on the rig still lets A/B swap without a new chassis |
| **Verdict** | **Working lead for the rig direction** — after this table is filled, not before. Clears the stop-path architecture, the three-contact cliff minimum, the battery-forward CoM lever, and the JGA25-class demand window on paper. Trail/`BM-07` glitch, dark/glossy TCRT failure, and P03 stall-current conflict remain open. **Not a freeze, not a purchase, not ADR-04/07 closure** | **Comparison retained; not waived.** No-trail `BM-07` and extra cliff headings are the reasons it exists. It loses `d_stop` at 0.50 if ToF stays telemetry-only; it spends C3 GPIO; ball denting/`U` rolling resistance are unowned. Keep it on the rig as the interchangeable front-support / ring-harness alternative. Do not silently drop it because A is the working lead |

## 3. Selected path (after the table)

**Installed V1 path (BD-08, `dimensional-baseline.md` v1.12, SCOPE-09 v1.3):** Concept A **chassis and sensing** (three look-downs, analog-IR in the stop path, motors on the axle, battery low and forward, JGA25-class) **plus `D21` ball transfer** as the front support.

Concept A as authored below remains the **caster paper concept**. Concept B remains the **ball + ring + ToF/bump** paper concept. The selected path takes axis 1 from B (the ball) and axes 2–4 from A. It does not freeze a SKU, pass G01–G06, authorize purchase, or close ADR-04.

- The rig still carries an interchangeable front support. `D20` caster is the required comparison swap.
- A miss on dent, jam, or drag iterates off `D21`; it does not quietly keep a failed ball.
- Concept B's in-WB motors, perimeter ring, and bump-only stop path are not taken.

## 4. What neither concept is allowed to do

- Place the battery on or behind the axle (HIGH_AFT).
- Put a stop-path sensor behind I2C-only or a GPIO expander.
- Close G03 with bump-only at follow speed.
- Quote `2.0 m/s²` as the robot's `a_tip`.
- Quietly shrink `a_peak` to hide a CoM miss (`physics.md` §2.5).
- Freeze 14 mm skid height or 70 mm reach. Recompute `h/d < x/h` at the ballast corner being scored.
- Let a motor-driver HAT choose the cliff sensors.

## 5. Handoff

| Document | What it takes from this comparison |
|---|---|
| `../drivetrain-screen-01.md` | JGA25-class as the reference-unit *class*; N20 as lower bound; 37D as upper bound; **BD-08 `D21` selected / `D20` required swap**; skid D30 adjustable |
| `../sensing-screen-01.md` | A's 3-channel + analog-IR stop-path vs B's ring + ToF telemetry; dark/glossy as the cliff failure mode |
| `../rig.md` | Interchangeable front support, `D21` selected; independent `x`/`h` ballast; skid 60–80 / 8–16 mm |
| `../decision.md` | Selected path ≠ ADR-04/07 gate close; **BD-08** is the support-type selection |

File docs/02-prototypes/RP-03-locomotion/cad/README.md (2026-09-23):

# CAD moved

Body, chassis, and base CAD now live in [`docs/02-prototypes/RP-06-cad/`](../../RP-06-cad/README.md).

| Former path here | Current path |
|---|---|
| `body-chassis/layout-02/` (active) | [`../../RP-06-cad/body-chassis/layout-02/`](../../RP-06-cad/body-chassis/layout-02/README.md) |
| `body-chassis/layout-01/` | [`../../RP-06-cad/body-chassis/layout-01/`](../../RP-06-cad/body-chassis/layout-01/README.md) |
| `decisions.md` | [`../../RP-06-cad/decisions.md`](../../RP-06-cad/decisions.md) |

RP-03 still owns intent, storyboard, physics, screens, rig, and gates. Do not put a second geometry tree here.

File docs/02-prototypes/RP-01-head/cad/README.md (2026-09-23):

# CAD moved

Head CAD now lives in [`docs/02-prototypes/RP-06-cad/head/`](../../RP-06-cad/head/).

Start at the [RP-06 CAD index](../../RP-06-cad/README.md). Active model: [Layout 04](../../RP-06-cad/head/layout-04/README.md) (Layout 03 preserved). Decisions: [HEAD-CAD-01…10](../../RP-06-cad/head/decisions.md).

RP-01 still owns intent, storyboard, physics, gates, rig, and actuator screening. Do not put a second geometry tree here.

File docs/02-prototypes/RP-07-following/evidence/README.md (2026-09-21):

# RP-07 evidence index

| Field | Value |
|---|---|
| Status | **Empty. No RP-07 recording or physical test has been executed.** |

Future evidence is organized by immutable run ID:

```text
evidence/
  RUN-ID/
    manifest.yaml
    test-plan-snapshot/
    configuration/
    calibration/
    logs/
    measurements/
    external-video/
    annotations/
    results.md
```

Each manifest records:

- test and gate revision;
- pilot/scored designation;
- date/operator/location/ambient/floor/lighting;
- subject/test-material consent and retention record where applicable;
- robot rig, ballast, hardware and harness revisions;
- OS/kernel/Picamera2/libcamera/runtime/model/source/config hashes;
- calibration revisions;
- clocks/time-sync method and external timing cue;
- instrument identifiers/checks and uncertainties;
- raw asset locations and hashes, including assets stored outside Git;
- deviations, faults, anomalies and terminal outcome.

Large frames/video may remain outside Git. The manifest must retain a stable asset identifier/path and cryptographic hash. A missing asset or revision makes that run incomplete for `RP07-G07`.

Do not add placeholder PASS files. A run directory exists only when evidence exists.

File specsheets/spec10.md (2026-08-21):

# MAKAD — SPEC-10
# Visual Novelty, Object Understanding & Semantic Perception
## Revised Final Specification

> **Design principle:** **Notice, then optionally name.**  
> Makad should react quickly to visual change without needing to understand it semantically. Semantic interpretation is slower, optional, behaviour-driven, and subordinate to real-time perception.

---

# 1. Scope of this specification

SPEC-10 defines Makad's **non-human visual novelty and semantic-understanding layer**.

It contains two deliberately different perception paths.

### Path A — visual novelty

Answers:

> **"Did something visually interesting just happen?"**

Examples:

- an object appears;
- an object disappears;
- something changes;
- something moves;
- Makad looks away, looks back, and the scene is different.

The output is an **attention-level perceptual event**, not an actuator command.

---

### Path B — semantic inspection

Answers:

> **"What is the thing Makad is currently looking at?"**

The canonical V1 interaction is **show-and-tell**:

1. a person presents an object;
2. Makad orients toward it;
3. Makad captures a suitable image;
4. Makad immediately enters an expressive "examining/thinking" state;
5. semantic inference occurs;
6. Makad receives a structured interpretation or explicit failure/uncertainty result.

Semantic inference is:

**trigger-driven → asynchronous → slow-path → lower priority than SPEC-09.**

---

## 1.1 Explicitly outside SPEC-10

SPEC-10 does not own:

- human detection/tracking;
- human target selection;
- real-time gaze control;
- face identification;
- person identity;
- persistent object identity;
- remembered object locations;
- SLAM;
- semantic mapping;
- room inventories;
- manipulation perception;
- grasp estimation;
- safety-grade obstacle ranging;
- safety-grade metric depth;
- autonomous navigation perception;
- continuous VLM scene narration;
- arbitrary pointing/reference resolution;
- OCR/general text reading;
- camera-history recording;
- long-term visual memory.

Persistent entity/object memory belongs to the later memory architecture.

---

# 2. Existing Makad decisions that constrain SPEC-10

## 2.1 SPEC-08 owns the camera

SPEC-10 shall use the common camera acquisition architecture.

It shall inherit rather than redefine:

- camera intrinsics;
- distortion treatment;
- frame timestamps;
- exposure metadata where available;
- camera extrinsics;
- image coordinate conventions;
- calibration data;
- camera/head transform.

There shall not be a second independent camera stack for semantic vision.

---

## 2.2 SPEC-09 owns the hard real-time visual loop

SPEC-09 remains responsible for:

**camera → human detection/tracking → target selection → gaze geometry → attention/gaze**

with its existing real-time timing requirements.

SPEC-10 shall never weaken those requirements.

When resources are insufficient:

> **SPEC-10 loses resources before SPEC-09 does.**

---

## 2.3 Shared capture-time geometry remains mandatory

SPEC-09 already established that directional observations must use the physical camera/head state corresponding to **image capture time**, not inference-completion time.

SPEC-10 inherits the same timestamp-synchronization requirement and shall not introduce a weaker timing standard.

Likewise, objects and novelty regions requiring a bearing shall use the same:

**pixel → camera ray → capture-time pose → neck/Makad frame**

pipeline used by SPEC-09.

---

## 2.4 SPEC-09's ego-motion model is inherited

SPEC-10 shall not create an independent optical-flow-based interpretation of Makad's own head motion.

The baseline compensation mechanism shall inherit SPEC-09's **kinematic feedforward** model.

Optical flow may later supplement it, but it shall not replace the shared kinematic model as the source of expected camera motion.

---

## 2.5 Coarse range remains non-safety information

Where camera translation relative to the neck pivot requires approximate depth/range for geometric correction, SPEC-10 may use the same coarse-range mechanism permitted by SPEC-09.

Such range remains:

**interaction geometry only — never collision/safety depth.**

---

## 2.6 Actual neck pose is a required perception input

SPEC-02 already requires measured physical neck pose to be available to perception.

SPEC-10 depends on:

- measured yaw;
- measured pitch;
- measured roll if present;
- timestamps;
- preferably estimated angular velocity.

Commanded servo angle alone is insufficient.

---

## 2.7 SPEC-10 creates an explicit build-order dependency

Unlike much of SPEC-09, several important SPEC-10 tests require the camera itself to move.

Therefore full novelty validation cannot happen before Makad has:

1. a controllable neck prototype;
2. timestamped physical joint-state measurements;
3. a candidate camera mounted approximately in its intended geometry.

This creates the following development milestone:

> **Prototype SPEC-10 novelty as soon as the neck mule can perform controlled representative motion, and do so before final camera and compute-platform lock.**

Waiting until final integration would be too late.

---

# 3. Engineering reasoning / architecture

# 3.1 Two paths remain fundamental

SPEC-10 is not one giant computer-vision pipeline.

```text
                        CAMERA
                           │
                ┌──────────┴───────────┐
                │                      │
                ▼                      ▼
        LIGHTWEIGHT NOVELTY      SEMANTIC INSPECTION
                │                      │
                │                      │
        provisional hint         triggered request
                │                      │
        confirmed hint           quality-gated frame
                │                      │
                ▼                      ▼
          attention system        local / remote
                                       │
                                       ▼
                               structured result
                                       │
                                       ▼
                                  behaviour
```

The novelty path exists primarily for **aliveness**.

The semantic path exists for **understanding on demand**.

---

# 3.2 Novelty needs a real latency architecture

The previous version left three independent variables unresolved:

- processing frequency;
- temporal persistence;
- cooldown.

Those parameters directly combine into reaction latency.

They therefore cannot be tuned independently without an end-to-end requirement.

SPEC-10 now uses a **two-stage novelty event**.

---

## Stage 1 — provisional novelty

A single sufficiently strong observation may produce:

`NOVELTY_PROVISIONAL`

This event is:

- low confidence;
- short lived;
- cheap;
- suitable for subtle behavioural acknowledgement.

The attention system may allow it to cause something like an **eyes-only glance**.

A provisional event shall not by itself authorize a full head turn.

### End-to-end latency

From the first camera frame containing usable evidence of the change to publication of the provisional attention hint:

\[
\boxed{T_{provisional} \leq 150\text{ ms}}
\]

---

## Stage 2 — confirmed novelty

Persistence or repeated evidence promotes the same visual episode to:

`NOVELTY_CONFIRMED`

A confirmed event may be allowed by the attention arbiter to trigger:

- physical head orientation;
- curious posture;
- chirp;
- further inspection.

### End-to-end latency

From the first usable camera frame containing the change to publication of the confirmed event:

\[
\boxed{T_{confirmed} \leq 400\text{ ms}}
\]

---

## Why the split exists

A one-frame false positive now costs Makad perhaps:

> a tiny eye flick.

It does **not** cost:

> a pointless mechanical head turn.

That converts the false-positive/latency tradeoff into two much easier decisions.

---

# 3.3 Derived novelty-processing cadence

For provisional latency:

\[
T_{provisional}
=
T_{wait}
+
T_{process}
+
T_{publish}
\]

To remain within 150 ms, the lightweight novelty path shall have:

\[
T_{wait} \leq 100\text{ ms}
\]

which implies an active evaluation cadence of at least approximately:

\[
\boxed{10\text{ Hz}}
\]

or another event-driven architecture providing an equivalent worst-case evaluation interval.

The remaining:

\[
\boxed{\leq50\text{ ms}}
\]

is allocated to:

- geometric compensation;
- change analysis;
- event formation;
- IPC/publication.

This is a much stronger compute constraint than simply saying "lightweight."

---

# 3.4 Eyes hide perception latency

This architecture deliberately matches Makad's established eye/head behaviour hierarchy:

**eyes signal attention first → physical head follows if warranted.**

SPEC-10 therefore does not need to eliminate all temporal validation.

Instead:

```text
visual change
    ↓
≤150 ms
    ↓
eyes notice
    ↓
additional evidence
    ↓
≤400 ms total
    ↓
head may follow
```

The character animation and perception architecture now reinforce each other.

---

# 3.5 Novelty cannot depend only on adjacent frames

Adjacent-frame novelty misses one of Makad's most important behaviours.

Example:

1. Makad looks at an empty desk.
2. Makad looks toward the user.
3. The user places a mug on the desk.
4. Makad later looks back.

The object never "appeared" between two frames viewing the desk.

It appeared while the desk was out of view.

Therefore SPEC-10 requires **pose-keyed visual reference memory**.

---

# 3.6 Pose-keyed reference frames

The novelty subsystem shall maintain a small cache of reference observations indexed primarily by measured head/camera pose.

Conceptually:

```text
reference_cache[
    quantized_yaw,
    quantized_pitch,
    quantized_roll
] → reference observation
```

When Makad returns to a previously observed viewing direction:

1. obtain capture-time physical head pose;
2. retrieve the nearest appropriate reference observation;
3. geometrically align the views where required;
4. compare current visual content against the prior view.

This supports:

> **look away → environment changes → look back → notice**

without requiring continuous observation of the change.

---

# 3.7 Kinematic ego-motion compensation

For camera rotation, the baseline frame warp shall derive from the same kinematic motion estimate used by SPEC-09.

For approximately pure camera rotation:

\[
H = K R K^{-1}
\]

where:

- \(K\) is the calibrated camera intrinsic matrix;
- \(R\) is the predicted relative camera rotation between captures.

This allows a previous view to be warped into the expected current view cheaply.

---

## 3.7.1 Important failure case: parallax

Makad's camera does not necessarily rotate about its optical centre.

Neck motion therefore creates some camera translation.

Residual parallax scales approximately with:

\[
\frac{\|\Delta t\|}{Z}
\]

where:

- \(\Delta t\) is relative camera translation;
- \(Z\) is object range.

Therefore kinematic homography compensation becomes weakest for **near objects**.

Ironically, that is exactly where show-and-tell occurs.

Consequently:

- pose-keyed comparisons should preferentially compare frames captured at closely matching physical poses;
- large-pose-difference homography comparisons shall not be treated as reliable close-range novelty evidence;
- coarse range may be used where already available;
- persistent close-range residuals shall not automatically become confirmed novelty.

---

# 3.8 Reference cache is not object memory

The reference cache exists only to answer:

> **"Does this view differ from the previous accepted appearance of this view?"**

It shall not create:

- named objects;
- persistent identities;
- object-location histories;
- semantic maps.

This remains perception infrastructure, not SPEC-20 memory.

---

# 3.9 Novelty event semantics

SPEC-10 shall support the following coarse visual-change categories:

- `appeared`
- `disappeared`
- `changed`
- `moved`
- `unknown_change`

`unknown_change` exists because reliably distinguishing motion from disappearance+appearance may not always be possible without stronger object correspondence.

The system shall prefer `unknown_change` over inventing precision.

---

# 3.10 Event coalescing is not habituation

SPEC-10 and the future behaviour/habituation layer must have a hard boundary.

### SPEC-10 event coalescing

Means:

> "Do not emit the same underlying visual episode repeatedly."

Example:

the same mug appearing should not create twenty identical novelty messages across twenty frames.

### SPEC-11 habituation / interest decay

Means:

> "This event is real, but Makad no longer finds it interesting."

SPEC-10 shall not reduce perceptual event validity merely because Makad has seen similar events many times.

Perception decides:

> **did it happen?**

Behaviour decides:

> **do I still care?**

---

# 3.11 Canonical V1 inspection geometry

"Show me this" needs a computable interpretation.

V1 therefore adopts a **centre-presentation convention**.

### Presentation zone

The intended object's visual centre should lie approximately within:

\[
u \in [0.30W, 0.70W]
\]

\[
v \in [0.30H, 0.70H]
\]

where \(W,H\) are image dimensions.

This corresponds to the central 40% of the image along each dimension.

---

### Default semantic crop

The initial semantic ROI shall be:

\[
u \in [0.20W,0.80W]
\]

\[
v \in [0.20H,0.80H]
\]

providing a margin around the presentation zone.

This gives V1 an explicit crop contract without requiring a separate class-agnostic object detector.

---

## 3.11.1 Why this is preferable for V1

The human performs most of the segmentation by:

> holding the thing up in front of Makad.

Makad does not need to solve arbitrary referring expressions just to demonstrate useful visual understanding.

---

# 3.12 Crop policy

The remote semantic path shall use the default inspection crop when that crop contains sufficient information.

A full frame may be sent only when:

- the behaviour explicitly requires scene context;
- or the semantic backend determines that the inspection crop is insufficient and policy allows a wider retry.

A class-agnostic objectness/segmentation stage is therefore **not a V1 prerequisite**.

It remains a possible later TARGET.

---

# 3.13 Pixels-on-target is a camera requirement

Near focus alone is insufficient.

For an object of physical width \(w\) at distance \(d\):

\[
\theta =
2\tan^{-1}\left(\frac{w}{2d}\right)
\]

For a representative:

\[
w=0.06\text{ m}, \qquad d=0.40\text{ m}
\]

the angular width is approximately:

\[
\boxed{\theta \approx 8.6^\circ}
\]

With calibrated horizontal focal length \(f_x\), the projected width is approximately:

\[
N_{px}
=
2f_x\tan\left(\frac{\theta}{2}\right)
\]

For intuitive comparison, with a roughly 70° horizontal FOV:

- a 1280-pixel-wide image gives roughly 150–160 pixels across such an object;
- a 640-pixel-wide image gives only roughly 75–80 pixels.

Therefore camera FOV, image width and semantic recognition performance are coupled.

SPEC-08 cannot lock the lens/camera merely because the object is "in focus."

---

# 3.14 Semantic pixels-on-target threshold

Define:

\[
N_{semantic}
\]

as the minimum projected target width required for acceptable semantic performance.

Unlike the geometry above, \(N_{semantic}\) depends on the actual semantic backend.

It shall therefore be established experimentally using the Makad object benchmark by progressively reducing effective object resolution.

Before final SPEC-08 camera lock, the candidate camera shall demonstrate:

\[
\boxed{
N_{object}(0.4\text{ m})
\geq
N_{semantic}
}
\]

for representative small show-and-tell objects.

This becomes a **component-selection gate**, not a generic future tuning parameter.

---

# 3.15 Semantic capture and motion

Slow inference does not require Makad to remain motionless.

The correct sequence is:

```text
orient / settle sufficiently
        ↓
capture candidate frames
        ↓
choose acceptable frame
        ↓
release motion restriction
        ↓
Makad resumes expressive "thinking"
        ↓
semantic inference continues
```

Makad only needs a sufficiently stable **capture opportunity**.

It does not need to freeze for two seconds while a VLM thinks.

---

# 3.16 Frame-quality gate

Semantic inference shall not consume arbitrarily bad frames.

The capture-quality system shall calculate at least:

### Blur metric

A focus/sharpness metric based on spatial high-frequency content, initially:

\[
Q_{blur} = \operatorname{Var}(\nabla^2 I)
\]

i.e. variance of Laplacian or equivalent.

Absolute thresholds depend strongly on:

- camera;
- resolution;
- exposure;
- preprocessing.

Therefore SPEC-08 camera validation shall establish an acceptable sharp-frame baseline.

The runtime gate shall compare against that calibrated baseline rather than using an arbitrary internet threshold.

---

### Exposure metric

For the semantic ROI:

\[
f_{clip}
=
\frac{
N_{dark-clipped}+N_{bright-clipped}
}{
N_{ROI}
}
\]

shall be measured.

The final acceptable clipping threshold shall be determined using the Makad camera/object benchmark.

---

### Motion state

Capture shall also consider measured head angular velocity.

A candidate frame taken during a high-speed neck movement shall be penalized or rejected when motion blur is expected.

---

# 3.17 Semantic acquisition is bounded

After a semantic request has entered its capture phase:

- maximum reacquisition attempts: **3**
- maximum total frame-acquisition window: **750 ms**

If no suitable source frame is obtained:

`epistemic_outcome = unusable_image`

The subsystem shall not loop indefinitely waiting for perfection.

Major gaze reorientation should normally occur **before** the semantic request enters capture.

---

# 3.18 Semantic result preserves spatial context

The semantic result shall retain the location of what was inspected.

At capture time, SPEC-10 shall calculate and attach:

- source ROI;
- source capture timestamp;
- ROI-centre camera ray;
- capture-time neck/Makad-frame bearing;
- angular ROI extent where practical;
- coarse range used for geometry, if any.

This enables later behaviour such as:

> Makad names an object and then keeps looking toward the same thing.

The bearing should not need to be reconstructed seconds after inference completion.

---

# 3.19 Semantic output has two orthogonal outcome axes

The previous single failure enumeration incorrectly mixed:

> **"I cannot tell what this is"**

with:

> **"the network is down."**

SPEC-10 shall separate them.

---

## Epistemic outcome

Describes the visual knowledge result.

Examples:

- `identified`
- `uncertain`
- `ambiguous_target`
- `unknown`
- `unusable_image`

---

## System outcome

Describes whether the computation itself succeeded.

Examples:

- `ok`
- `offline`
- `timeout`
- `cancelled`
- `privacy_blocked`
- `resource_rejected`
- `backend_error`

Thus:

```text
system_outcome = ok
epistemic_outcome = unknown
```

means:

> the visual system worked correctly but could not identify the object.

While:

```text
system_outcome = offline
epistemic_outcome = null
```

means:

> Makad could not access the requested backend.

Behaviour can react differently to each.

---

# 3.20 Local versus remote semantic path

V1 architecture remains backend-independent.

### Open-vocabulary backend

A remote VLM is acceptable and likely useful for V1 show-and-tell.

### Local closed-set backend

Remains a TARGET if a real Makad behaviour requires specific known classes.

The architecture shall not require both before the capability is considered functional.

---

# 3.21 "Preemptible inference" is removed

SPEC-10 shall **not assume** that inference already executing on:

- GPU;
- NPU;
- DSP;
- accelerator

can be interrupted.

Often it cannot.

Instead the architecture distinguishes:

### request cancellation

Makad can decide a semantic result is no longer needed.

from:

### hardware execution preemption

which may be impossible.

Therefore accelerator safety must be handled **before scheduling the work**.

---

# 3.22 Shared accelerator occupancy contract

Define:

\[
J_{9,shared}
\]

as the maximum additional scheduling delay that SPEC-09 can tolerate from another workload while still satisfying its finalized real-time latency/jitter requirements.

For any non-preemptible semantic operation sharing SPEC-09's accelerator:

\[
\boxed{
T_{nonpreemptible}
\leq
J_{9,shared}
}
\]

shall hold.

The actual numeric value shall be inherited from the finalized SPEC-09 timing budget during master-spec consolidation.

This is not a free SPEC-10 TARGET.

It is a **cross-spec derived constraint**.

If the candidate semantic model cannot satisfy it, one of the following must happen:

1. semantic inference runs remotely;
2. semantic inference runs on a separate accelerator;
3. semantic work is segmented/chunked sufficiently;
4. semantic inference is blocked while SPEC-09 tracking requires the device.

"Thread priority" is not an acceptable fix for a non-preemptible accelerator operation.

---

# 3.23 Memory bandwidth is also shared

Accelerator occupancy is only half the problem.

A semantic model can degrade SPEC-09 by saturating:

- DRAM bandwidth;
- shared cache;
- memory controller;
- thermal envelope.

Therefore coexistence validation must measure SPEC-09 performance during the **actual semantic memory load**, not merely confirm that its process has a higher scheduler priority.

---

# 3.24 Privacy architecture

Remote visual inference is not equivalent to ordinary local camera operation.

SPEC-10 therefore introduces a single architecture concept:

# Visual Uplink Gate

All outbound network transmission containing camera-derived visual data shall pass through one controlled uplink mechanism.

No semantic backend shall directly upload camera images independently.

The Visual Uplink Gate owns:

- privacy-mode checking;
- image/crop authorization;
- transfer state;
- remote-analysis indication;
- logging of backend/version;
- completion/failure state.

---

# 3.25 Global local-only mode

Makad shall expose a global mode equivalent to:

`visual_cloud_enabled = false`

When local-only mode is active:

> **no camera-derived image data may leave the device.**

This policy overrides:

- semantic routing;
- behaviour requests;
- novelty events;
- backend preferences.

A fresh/default privacy configuration should begin in local-only mode until remote visual inference is intentionally enabled.

---

# 3.26 Privacy indication uses Makad's own expression language

Remote visual transmission shall not silently occur.

When the Visual Uplink Gate is actively transmitting/awaiting a remote visual request, Makad shall display a distinct **uplink visual state using its existing eye display**.

It shall:

- preserve the eyes-only face rule;
- not require text;
- not require a generic cloud icon;
- be visually distinguishable from ordinary idle/thinking expressions.

Possible implementation:

- distinctive eye pulse;
- brightness pattern;
- animation cadence;
- colour alteration if the final display supports colour.

The exact artwork belongs to the face/behaviour implementation.

The existence of a distinct state does not.

---

## 3.26.1 Indicator coupling

The uplink indicator shall be asserted by the **same Visual Uplink Gate that performs the transfer**.

It shall become active before camera-derived payload transmission begins and shall remain active until that remote visual operation finishes or fails.

A separate unrelated UI call is insufficient.

This prevents future code from accidentally uploading an image while forgetting to activate the indicator.

---

# 3.27 No cloud inference from novelty alone

A novelty event may trigger:

- eyes;
- head orientation;
- local curiosity behaviour.

It may not by itself authorize remote transmission.

A separate behaviour/semantic request must cross the privacy gate.

---

# 3.28 Reproducibility is a first-class requirement

SPEC-10 contains several interacting novelty thresholds and temporal policies.

Manual room testing is too slow for tuning.

Therefore the novelty system requires deterministic offline replay.

---

## Required replay recording

Record at minimum:

- image/frame data used by novelty;
- camera capture timestamps;
- measured yaw/pitch/roll;
- joint-state timestamps;
- camera exposure/gain metadata where available;
- calibration version;
- novelty configuration;
- relevant attention-state metadata.

The recording must preserve the camera/joint temporal relationship.

A frame recording without joint-state timing is insufficient.

---

## Replay requirement

Given the same recording, calibration and configuration, the novelty path shall reproduce the same event sequence and timestamps within the pipeline's defined deterministic granularity.

For the lightweight novelty path, fixed-input replay should be deterministic enough for automated regression tests.

Remote VLM outputs are explicitly exempt from bit-identical replay.

---

# 3.29 Semantic backends require version traceability

Every semantic result shall record where practical:

- provider;
- model identifier;
- immutable model version if exposed;
- API/version identifier;
- relevant inference configuration;
- request date/time.

If a provider exposes only a mutable model alias, that backend shall be marked as **not fully reproducible**.

The Makad object benchmark must be executable again whenever:

- model/backend configuration changes;
- a local model changes;
- a remote model version changes;
- a meaningful perception regression is suspected.

---

# 4. Formal requirements

## 4.1 Governing principles

The following are architectural principles rather than ordinary pass/fail feature requirements:

### P10-01 — Behaviour bounded

Semantic recognition exists because a Makad behaviour consumes the result.

### P10-02 — Notice before naming

Novelty detection shall not depend on semantic classification.

### P10-03 — Current observation is not memory

A visual result describes the captured observation and does not establish persistent object identity.

### P10-04 — Human social attention outranks incidental object curiosity

Unless behaviour explicitly overrides it, active human interaction remains higher priority than object novelty.

These principles are intentionally removed from the MUST count.

---

# 4.2 Critical architecture requirements

## C10-R01 — MUST — Shared camera pipeline

SPEC-10 shall consume the common SPEC-08 camera acquisition pipeline and shall not open a competing independent camera stream.

---

## C10-R02 — MUST — Shared perception geometry

All physical bearings generated by SPEC-10 shall use the same geometry implementation and conventions as SPEC-09.

---

## C10-R03 — MUST — Capture-time physical pose

Directional results shall use physical camera/head state corresponding to image capture time.

SPEC-10 inherits SPEC-09's finalized timestamp-synchronization requirement.

---

## C10-R04 — MUST — Shared kinematic ego-motion model

Expected image motion caused by commanded/measured head motion shall use SPEC-09's kinematic feedforward model as the baseline mechanism.

---

## C10-R05 — MUST — No direct actuation

SPEC-10 shall publish perception events/attention hints only.

No bounding box, novelty region or semantic ROI may directly command a motor.

---

## C10-R06 — MUST — SPEC-09 compute protection

SPEC-10 shall not cause SPEC-09 to violate its finalized latency, jitter or tracking requirements.

---

## C10-R07 — MUST — Shared accelerator occupancy bound

Any non-preemptible SPEC-10 work scheduled on a hardware accelerator shared with SPEC-09 shall satisfy:

\[
T_{nonpreemptible}\leq J_{9,shared}
\]

or shall not be scheduled while the real-time SPEC-09 workload requires that accelerator.

---

## C10-R08 — MUST — Memory/thermal coexistence

SPEC-10 shall also be limited where required to prevent shared memory-bandwidth or thermal contention from violating SPEC-09 requirements.

---

# 4.3 Novelty requirements

## C10-R09 — MUST — Local novelty

Basic novelty detection shall function without internet access.

---

## C10-R10 — MUST — Evaluation interval

While novelty monitoring is active, eligible novelty evaluations shall occur with a maximum nominal interval of:

\[
\boxed{\leq100\text{ ms}}
\]

or equivalent event-driven latency.

---

## C10-R11 — MUST — Provisional novelty latency

A qualifying visual change shall produce a provisional novelty event within:

\[
\boxed{\leq150\text{ ms}}
\]

of the first usable camera frame containing the change.

---

## C10-R12 — MUST — Confirmed novelty latency

A visual change satisfying the confirmation policy shall produce a confirmed novelty event within:

\[
\boxed{\leq400\text{ ms}}
\]

of the first usable evidence frame.

---

## C10-R13 — MUST — Two-tier novelty output

Novelty events shall explicitly indicate:

- `provisional`
- or `confirmed`.

---

## C10-R14 — MUST — Pose-keyed reference cache

Novelty shall support comparison against previously observed views indexed by physical camera/head pose rather than relying exclusively on adjacent-frame differences.

---

## C10-R15 — MUST — Look-away/look-back novelty

A scene change occurring while the changed region is outside Makad's current FOV shall remain detectable when Makad subsequently returns to a sufficiently similar prior viewing pose.

---

## C10-R16 — MUST — Egomotion robustness

Normal Makad head motion shall not systematically become confirmed environmental novelty.

---

## C10-R17 — MUST — Global disturbance rejection

The novelty system shall reject or reduce responses to:

- global exposure changes;
- camera gain transitions;
- broad illumination changes;
- expected full-frame displacement from head motion.

---

## C10-R18 — MUST — Novelty event contract

Every novelty event shall expose at minimum:

- `episode_id`;
- `phase = provisional | confirmed`;
- `event_kind`;
- source timestamp;
- source ROI;
- novelty strength/quality;
- physical bearing where valid;
- event age/expiry;
- confidence/validity state.

`event_kind` shall support:

- `appeared`;
- `disappeared`;
- `changed`;
- `moved`;
- `unknown_change`.

---

## C10-R19 — MUST — Attention hint

Qualified novelty events shall be representable through the common Makad `attention_hint` architecture.

---

## C10-R20 — MUST — Provisional/confirmed behavioural distinction

The attention interface shall preserve sufficient information for behaviour to allow:

- provisional event → subtle/eyes-only acknowledgement;
- confirmed event → possible physical head attention.

SPEC-10 does not itself command those motions.

---

## C10-R21 — MUST — Event coalescing

Repeated frames representing the same underlying visual episode shall be coalesced under the same episode rather than generating a new novelty event on every frame.

This is duplicate suppression only.

It shall not implement long-term interest/habituation.

---

## C10-R22 — TARGET — Human-region suppression

Where SPEC-09 human masks/tracks are available, SPEC-10 should suppress duplicate novelty events already explained by ordinary tracked human motion.

---

# 4.4 Semantic inspection requirements

## C10-R23 — MUST — Trigger-driven semantic inference

Computationally expensive semantic interpretation shall run only in response to an explicit semantic/behaviour request.

---

## C10-R24 — MUST — Defined V1 inspection region

V1 shall use the centre-presentation convention defined in §3.11.

The default semantic crop shall be the central 60% × 60% of the image unless another explicitly selected ROI is available.

---

## C10-R25 — MUST — Ambiguous target

If the semantic input contains multiple plausible intended objects and the target cannot be determined reliably:

`epistemic_outcome = ambiguous_target`

shall be permitted.

---

## C10-R26 — MUST — Close-range semantic compatibility

SPEC-08 camera selection shall demonstrate usable semantic imaging at the intended show-and-tell region including approximately:

\[
\boxed{0.4\text{ m}}
\]

---

## C10-R27 — MUST — Pixels-on-target gate

Before camera lock, the candidate camera/FOV/resolution combination shall demonstrate:

\[
N_{object}(0.4\text{ m})\geq N_{semantic}
\]

for representative small handheld objects.

---

## C10-R28 — MUST — Frame-quality measurements

Semantic candidate images shall be evaluated using at minimum:

- a calibrated blur/sharpness metric;
- ROI exposure/clipping metric;
- head-motion state.

---

## C10-R29 — MUST — Bounded capture

A semantic request entering frame-acquisition state shall terminate that phase within:

\[
\boxed{\leq750\text{ ms}}
\]

with no more than:

\[
\boxed{3}
\]

reacquisition attempts.

Failure shall produce `unusable_image`.

---

## C10-R30 — TARGET — Burst-based source-frame selection

Where compute/buffering permits, the system should select the best image from a short capture burst rather than trusting a single arbitrary frame.

---

## C10-R31 — MUST — Bearing retention

Every semantic result associated with a spatial target shall retain the capture-time bearing and ROI of the inspected region.

---

## C10-R32 — MUST — Backend-independent semantic result

Makad behaviour shall consume a common semantic result contract rather than provider-specific VLM responses.

---

## C10-R33 — MUST — Open-vocabulary path

V1 shall contain at least one usable open-vocabulary semantic path.

A remote VLM is acceptable.

---

## C10-R34 — TARGET — Local closed vocabulary

A local recognizer may be implemented for a small behaviour-relevant vocabulary if useful.

---

## C10-R35 — TARGET — Semantic backend routing

Where multiple backends exist, routing may consider:

- network availability;
- privacy mode;
- workload;
- vocabulary;
- requested behaviour;
- backend capability.

---

# 4.5 Semantic state and uncertainty

## C10-R36 — MUST — Early processing state

After a semantic request is accepted, behaviour shall receive a processing state rapidly enough to begin the thinking animation.

Target:

\[
\boxed{\leq150\text{ ms}}
\]

from request acceptance.

This does not constrain inference completion.

---

## C10-R37 — MUST — Orthogonal result taxonomy

Semantic output shall contain separate:

- `system_outcome`;
- `epistemic_outcome`.

---

## C10-R38 — MUST — Explicit uncertainty

Semantic output shall support:

- identified;
- uncertain;
- ambiguous;
- unknown.

It shall not force a label.

---

## C10-R39 — MUST — No fake calibrated confidence

Uncalibrated VLM self-confidence shall not be exposed as though it were calibrated perception probability.

Categorical confidence may be used instead.

---

## C10-R40 — MUST — Behaviour-accessible hedging

The behaviour layer shall be able to distinguish a confident semantic result from a weak/uncertain one and react differently.

---

# 4.6 Request scheduling

## C10-R41 — MUST — Bounded semantic queue

V1 semantic inference shall support at most one active inference request and a bounded number of pending requests.

An unlimited queue is prohibited.

---

## C10-R42 — MUST — Stale result rejection

Every semantic inference shall carry an interaction/request identifier.

A result from a cancelled or superseded interaction shall not automatically trigger behaviour.

---

## C10-R43 — MUST — Cancellation without preemption assumption

Semantic requests may be cancelled logically.

The architecture shall not assume cancellation can interrupt an already running accelerator kernel/model execution.

---

# 4.7 Privacy requirements

## C10-R44 — MUST — Visual Uplink Gate

All outbound camera-derived visual data shall pass through one privacy-aware network transfer mechanism.

---

## C10-R45 — MUST — Global local-only mode

When local-only mode is enabled, no camera-derived visual payload may leave Makad.

---

## C10-R46 — MUST — Novelty cannot authorize upload

A novelty event alone shall never authorize cloud image transfer.

---

## C10-R47 — MUST — Uplink indication

Every remote visual operation shall activate a distinct Makad eye/display state indicating remote visual processing.

---

## C10-R48 — MUST — Indicator-transfer coupling

The indication shall be controlled by the same Visual Uplink Gate performing the remote transfer and shall activate before outbound image data begins.

---

## C10-R49 — MUST — Minimum-necessary visual payload

For V1 show-and-tell, the default centre inspection crop shall be used rather than a full room frame whenever sufficient.

---

## C10-R50 — MUST — No persistent image storage by default

Semantic-request source images shall not enter long-term storage by default.

---

## C10-R51 — MUST — No raw-image operational logs

Normal runtime logs shall not contain raw camera frames unless explicit development image logging has been enabled.

---

# 4.8 Reproducibility and observability

## C10-R52 — MUST — Novelty replay recording

The development/validation system shall be able to record synchronized:

- camera frames;
- frame timestamps;
- measured joint state;
- joint timestamps;
- camera metadata;
- calibration identifier;
- novelty configuration.

---

## C10-R53 — MUST — Deterministic novelty replay

The novelty pipeline shall support deterministic offline replay sufficiently stable for regression testing of event generation.

---

## C10-R54 — MUST — Backend/version logging

Semantic logs shall record:

- backend/provider;
- model name;
- version where available;
- API/configuration information sufficient to identify the evaluated setup.

---

## C10-R55 — MUST — Runtime health

SPEC-10 shall expose:

- novelty active/inactive;
- novelty event rate;
- semantic queue state;
- backend;
- backend/version;
- remote/local path;
- inference latency;
- resource rejection;
- timeout;
- cancellation;
- error state.

---

## C10-R56 — MUST — Failure isolation

SPEC-10 process/backend/network failure shall not stop:

- SPEC-08 camera acquisition;
- SPEC-09 human tracking;
- gaze control;
- motor control.

---

# 4.9 Evaluation

## C10-R57 — MUST — Makad-specific object benchmark

Semantic evaluation shall use approximately:

\[
\boxed{30}
\]

physical objects representative of Makad's real environment.

---

## C10-R58 — MUST — Real operating conditions

The benchmark shall include:

- Makad's camera;
- actual/candidate mount geometry;
- approximately 0.4 m presentation;
- multiple orientations;
- realistic indoor lighting;
- handheld presentation;
- some object motion;
- representative head movement where relevant.

---

## C10-R59 — MUST — Error taxonomy in evaluation

Evaluation shall separately record:

1. useful/correct answer;
2. acceptable uncertainty/refusal;
3. confidently wrong answer;
4. system failure.

A generic accuracy percentage is insufficient.

---

## C10-R60 — MUST — Benchmark rerunnability

The 30-object suite shall be rerunnable on demand after backend/model/camera/configuration changes.

---

# 5. Interfaces and dependencies

# 5.1 SPEC-08 — Camera

SPEC-10 imposes **two** camera-selection gates:

### Optical focus

Representative objects must be sufficiently sharp around the 0.4 m interaction region.

### Semantic sampling

Representative small objects must provide sufficient pixels-on-target:

\[
N_{object}\geq N_{semantic}
\]

These requirements must be checked together with SPEC-09's wider human-tracking FOV requirement before lens/camera lock.

This is a genuine cross-spec tradeoff:

> wider FOV helps human coverage but reduces pixels-per-degree for small objects.

---

# 5.2 SPEC-09 — Human tracking/gaze

SPEC-10 requires:

- shared capture-time geometry;
- shared kinematic camera-motion model;
- attention-hint interface;
- real-time compute/jitter budget;
- optional person masks/tracks.

SPEC-10 shall not alter SPEC-09 merely because a semantic model is computationally expensive.

---

# 5.3 SPEC-02 — Neck mechanism

Full SPEC-10 novelty validation requires:

- working powered roll/pitch/yaw motion;
- measured roll state;
- measured physical pose;
- pose timestamps;
- representative camera mounting.

This makes the moving neck mule a prerequisite for meaningful novelty validation.

---

# 5.4 Behaviour / attention system

SPEC-10 publishes:

```text
novelty_provisional
novelty_confirmed
attention_hint
semantic_processing
semantic_result
semantic_system_failure
```

Behaviour determines:

- eye flick;
- head turn;
- ignore;
- curiosity;
- semantic inspection;
- chirp;
- hedging;
- request for another view.

---

# 5.5 SPEC-11 boundary

SPEC-10 performs **event coalescing**.

SPEC-11 performs **interest/habituation**.

No long-duration "I've seen this too often" decay belongs in SPEC-10.

---

# 5.6 Compute architecture

Compute selection must explicitly benchmark simultaneous:

- SPEC-09 tracking;
- novelty at ≥10 Hz equivalent;
- semantic preprocessing;
- local semantic inference if implemented;
- audio;
- normal Makad control.

Important resources include:

- accelerator occupancy;
- DRAM bandwidth;
- CPU utilization;
- memory pressure;
- thermals.

---

# 5.7 Privacy / networking

All camera-derived remote traffic shall pass through the Visual Uplink Gate.

Backend libraries shall not own unrestricted direct image-upload paths.

---

# 6. Quantities still requiring validation

The list is now much shorter.

## 6.1 \(J_{9,shared}\)

This is not independently tuneable by SPEC-10.

It must be copied/derived from final SPEC-09 real-time jitter headroom during consolidation.

---

## 6.2 Pose-cache angular bin/tolerance

Needs testing against:

- neck repeatability;
- camera FOV;
- scene distance;
- registration quality.

Too narrow → cache misses.

Too wide → excessive registration/parallax error.

---

## 6.3 Reference-background replacement policy

Need determine how long a changed scene must remain stable before it becomes the new accepted reference.

This affects duplicate-event generation but must remain separate from behavioural habituation.

---

## 6.4 Blur calibration threshold

Calibrate from accepted/rejected source frames with the final candidate camera.

---

## 6.5 Exposure clipping threshold

Calibrate using the actual Makad object test set and indoor lighting.

---

## 6.6 \(N_{semantic}\)

Must be measured for the selected semantic backend by testing reduced effective pixels-on-target.

This value must be known **before camera/FOV lock**.

---

## 6.7 Final semantic timeout

Ordinary semantic inference may take seconds.

The timeout should be selected from actual backend latency distributions rather than guessed.

---

## 6.8 Local recognition vocabulary

Only required if real behaviours justify it.

---

# 7. Acceptance tests

# C10-T01 — Shared camera/geometry inspection

Verify architecturally and through logs that SPEC-10:

- uses the common camera acquisition path;
- uses the common geometry implementation;
- consumes capture-time physical joint state.

**Pass:** no duplicate camera ownership or independently defined coordinate transform exists.

---

# C10-T02 — Provisional novelty latency

Introduce a clear new object while recording camera timestamps and novelty-event timestamps.

Measure:

\[
T =
t_{provisional}
-
t_{first\ usable\ evidence}
\]

**Pass:**

\[
\boxed{T\leq150\text{ ms}}
\]

for the required latency percentile established for Makad's real-time event tests.

---

# C10-T03 — Confirmed novelty latency

Repeat C10-T02 and measure confirmed-event publication.

**Pass:**

\[
\boxed{T\leq400\text{ ms}}
\]

for qualifying persistent novelty.

---

# C10-T04 — Provisional false-positive behaviour

Create brief one-frame/transient disturbances.

**Pass:**

Transient evidence may produce a provisional event but shall not automatically become a confirmed event or full head-attention command.

---

# C10-T05 — Moving-camera compensation

Use a static room.

Command representative neck:

- yaw;
- pitch;
- combined movement.

**Pass:**

Makad's own motion does not systematically produce confirmed novelty.

---

# C10-T06 — Look-away / object-appears / look-back

1. View an empty desk at pose A.
2. Turn Makad to pose B.
3. Place an object on the desk.
4. Return to approximately pose A.

**Pass:**

The pose-keyed reference mechanism detects the changed scene.

Provisional and confirmed latency budgets apply from the first usable returned-view frame.

---

# C10-T07 — Look-away / object-disappears / look-back

1. Establish a stable reference containing an object.
2. Look away.
3. Remove the object.
4. Return.

**Pass:**

A disappearance/change event is generated without requiring the removal itself to have been visible.

---

# C10-T08 — Pose-cache false-change test

Return repeatedly to approximately the same reference pose without changing the scene.

**Pass:**

Normal neck repeatability and registration error do not repeatedly create confirmed novelty.

---

# C10-T09 — Global illumination/exposure disturbance

Apply representative lighting and auto-exposure changes without introducing a localized object event.

**Pass:**

The system does not systematically emit high-confidence localized confirmed novelty.

---

# C10-T10 — Event-coalescing test

Introduce one object and leave it unchanged.

**Pass:**

One visual episode is generated rather than a new confirmed event every processing cycle.

---

# C10-T11 — Static-room soak

Operate Makad for:

\[
\boxed{\geq1\text{ hour}}
\]

in an ordinary unchanged indoor environment with representative idle neck motion enabled.

No deliberate scene changes are introduced.

### V1 confirmed false-event target

\[
\boxed{\leq2\ confirmed\ false\ novelty\ events/hour}
\]

Provisional events may occur more frequently because they have substantially lower behavioural cost.

The important product criterion is that Makad does not repeatedly perform false curiosity/head-attention reactions.

---

# C10-T12 — Human-attention priority

Establish active SPEC-09 human interaction.

Create an incidental confirmed object novelty elsewhere.

**Pass:**

The event reaches arbitration but does not automatically steal physical attention from the active human target.

---

# C10-T13 — Offline deterministic replay

Record a validation sequence containing:

- head motion;
- scene changes;
- look-away/look-back;
- exposure changes.

Replay the same camera/joint data repeatedly.

**Pass:**

The novelty system produces the same event sequence and materially identical timing classification under identical configuration.

---

# C10-T14 — Replay parameter iteration

Modify one novelty threshold/persistence policy and replay the same recording.

**Pass:**

The developer can objectively compare:

- event latency;
- provisional count;
- confirmed count;
- false positives

without physically repeating the scene.

---

# C10-T15 — Show-and-tell target geometry

Present an object centred within the defined presentation zone.

**Pass:**

The default semantic crop contains the intended object with sufficient surrounding margin for useful semantic interpretation.

---

# C10-T16 — Multiple-object ambiguity

Place multiple plausible objects in the inspection crop without one clearly satisfying the presentation convention.

**Pass:**

The system can return:

`ambiguous_target`

instead of confidently inventing target selection.

---

# C10-T17 — 0.4 m focus test

Present representative objects around:

\[
\boxed{0.4\text{ m}}
\]

from the camera.

**Pass:**

Candidate frames satisfy the calibrated sharpness requirement.

---

# C10-T18 — Pixels-on-target test

Measure projected width of representative small objects at the show-and-tell distance.

**Pass:**

\[
\boxed{
N_{object}
\geq
N_{semantic}
}
\]

for the candidate camera/FOV configuration.

Failure blocks final camera selection.

---

# C10-T19 — Backend resolution-degradation test

Using the Makad object set, progressively reduce effective target resolution.

Measure:

- correct answers;
- uncertainty;
- confidently wrong answers.

Determine:

\[
N_{semantic}
\]

at the chosen acceptable quality point.

This test shall occur before final camera lock.

---

# C10-T20 — Frame-quality blur test

Collect deliberately:

- sharp;
- moderately blurred;
- severely motion-blurred

frames.

Compute the configured blur metric.

**Pass:**

The quality gate reliably rejects frames known to be unusable using thresholds calibrated for the chosen camera.

---

# C10-T21 — Exposure-quality test

Provide:

- acceptable exposure;
- severe highlight clipping;
- severe shadow clipping.

**Pass:**

The exposure metric identifies unusable cases sufficiently for semantic capture gating.

---

# C10-T22 — Acquisition timeout

Continuously prevent acquisition of a valid semantic frame.

**Pass:**

Within:

\[
\boxed{\leq750\text{ ms}}
\]

and after no more than:

\[
\boxed{3}
\]

reacquisition attempts, the request terminates with:

`epistemic_outcome = unusable_image`.

---

# C10-T23 — Bearing retention

Present and semantically inspect an object.

After inference completes, inspect the semantic result.

**Pass:**

The result still contains:

- source ROI;
- capture timestamp;
- capture-time physical bearing.

A late behaviour can therefore orient toward the original observation without reconstructing geometry from the current head pose.

---

# C10-T24 — Orthogonal failure taxonomy

Exercise:

1. visually ambiguous object with functioning backend;
2. unknown object;
3. network disconnection;
4. backend timeout.

**Pass:**

Visual uncertainty appears in `epistemic_outcome`.

Infrastructure failure appears in `system_outcome`.

They are not conflated.

---
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

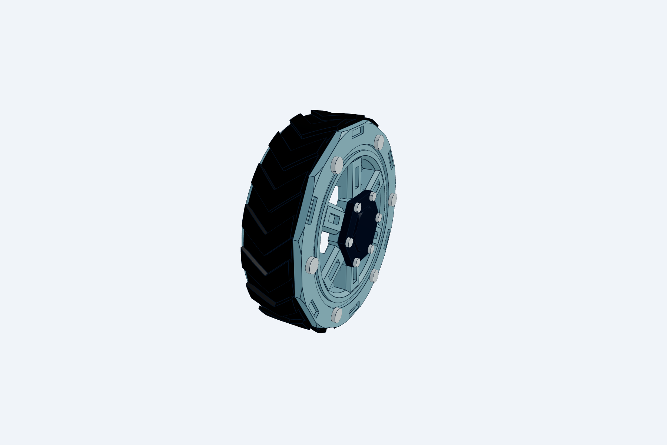
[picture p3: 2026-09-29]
docs/03-build/01-chassis/v1/cad/wheel/snapshots/tread_20260929T085508Z.png

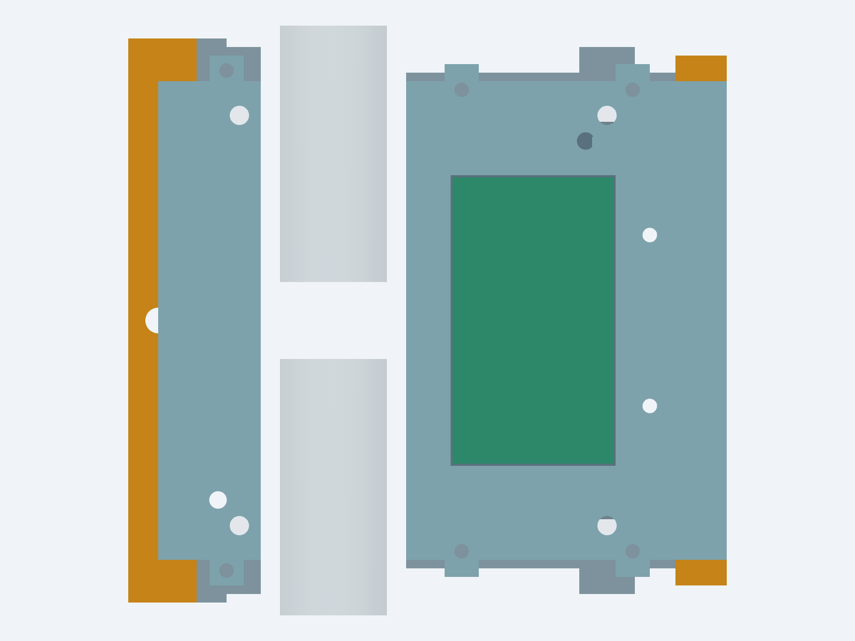
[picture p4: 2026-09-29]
docs/03-build/01-chassis/v1/cad/frame-split/frame-split-release-review-top_20260929T092844Z.png

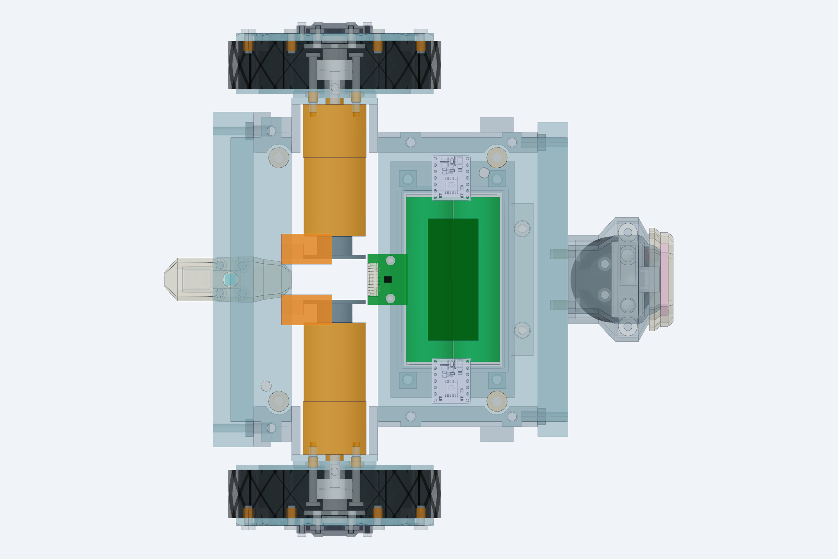
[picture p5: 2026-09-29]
docs/03-build/01-chassis/v1/cad/chassis-v1-merged-top_20260929T094145Z.png

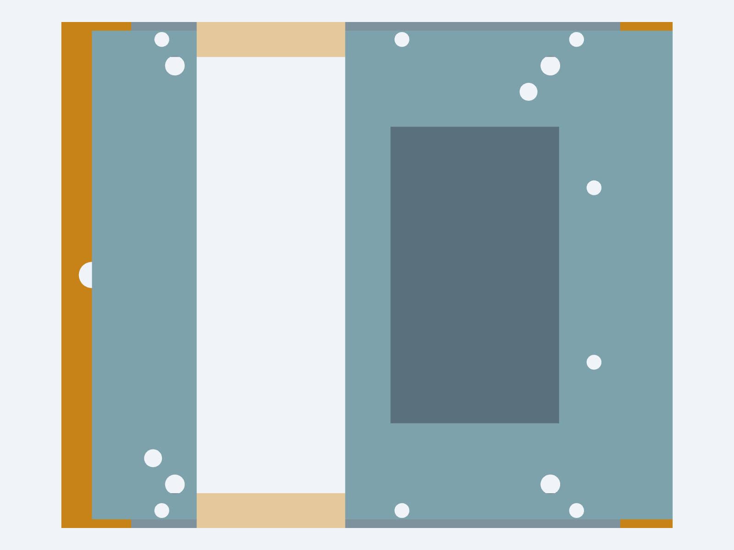
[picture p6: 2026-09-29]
docs/03-build/01-chassis/v1/cad/frame-split/frame-split-top_20260929T091454Z.png

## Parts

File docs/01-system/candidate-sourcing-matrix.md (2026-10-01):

# Makad V1 Candidate Sourcing Matrix

| Field | Value |
|---|---|
| Status | **Living. Face display, head camera, C2, Raspberry Pi 5 2 GB, official Pi Active Cooler and C3 prototype controller are selected; remaining rows are candidates unless explicitly marked otherwise.** |
| Version | 0.31 |
| Owner | Project builder |
| Created | 2026-08-17 |
| Last reviewed | 2026-09-19 |
| Governed by | `risk-prototype-plan.md` §"Continuous sourcing and data workstream" (deliverable 1) |
| Feeds | First project cost range (CON-TBD-13), RP-01…RP-07 inputs, later BOM |

The current dimensional baseline selects the two-powered-wheel/**front ball transfer**/rear-skid topology and major packaging targets. The project builder has additionally selected the **Waveshare ESP32-S3-LCD-4.3, no-touch, SKU 30493** as the V1 face display, the **Raspberry Pi Camera Module 3 Wide, visible-light/IR-cut, order code SC0874** as the V1 head camera, **C2: Waveshare ESP32-S3-Zero**, **C3 prototype: Espressif ESP32-S3-DevKitC-1-N8**, **Raspberry Pi 5 2 GB** as the body-mounted main compute and the **official Pi 5 Active Cooler**. C1 is closed and rejected on the selected display carrier's GPIO budget. The motor driver, actuator, battery, storage, framework, production camera interconnect and all purchase authorizations remain open. XC330-M288-T is the first named RP-01 paper candidate (C01); it is not selected and does not authorize purchase. Every other purchasable row remains a candidate chosen to bound specification, availability and landed cost. Prices/stock are dated India planning snapshots and **must be re-checked immediately before purchase** (same rule as `workbench.md`). Bench tooling is not repeated here — it lives in `workbench.md`.

Columns follow the plan's required fields (line 102): spec, supplier, availability, lead time, substitute, quantity, landed cost, replacement risk, required tools, fabrication dependency.

## Compute & control

`RP02-P3-REG-01` fixes the C0/C2/C3/D1 ownership: the display carrier renders the face, C2 owns head trajectories/safety, C3 owns base control/local hazards, and the Pi owns semantic behaviour/perception. Production MCU links are differential UART and C2 relays display state locally. Rows below are candidates unless explicitly marked selected; detailed `CCD-*` evidence lives in `RP-02-electrical/compute-control-component-screen.md`.

| Component | Candidate spec | Supplier (candidate) | Avail. | Lead | Substitute | Qty | Landed ₹ (est.) | Replacement risk | Required tools | Fab dependency |
|---|---|---|---|---|---|---:|---:|---|---|---|
| **Main compute (SBC) — SELECTED** | **Raspberry Pi 5, 2 GB**, selected 2026-09-16 under `RP02-P2-REG-02`: supported IMX708/libcamera path, body-mounted, with 22-to-15-pin CSI cable and dedicated 5.1 V nominal / 5 A-capable compute branch. Pi 5 1 GB is rejected for the first build because its captured ₹555 saving halves RAM; a constrained 2 GB run is only a pre-screen, not proof on actual 1 GB hardware. Pi 5 4 GB is the fallback only if measured memory proves insufficient. | [Silverline](https://www.silverlineelectronics.in/products/raspberry-pi-5-model-b-2gb-ram) ₹6,455 in stock; [Robocraze](https://robocraze.com/products/raspberry-pi-5-model-2gb-ram) ₹7,869, self-described authorized seller (2026-09-16; reconfirm) | Silverline in stock; Robocraze collection availability conflicted | 0–7 d | Pi 5 4 GB only on measured memory failure | 1 | **≈ 6,455–7,869 board-only** | Med — price/stock spread; exact authorized channel and warranty at checkout | — | Case/mount printed; exact power-entry hardware open |
| **Pi 5 cooler — SELECTED** | **Official Raspberry Pi 5 Active Cooler**, temperature-controlled blower with tach/PWM | [Silverline](https://www.silverlineelectronics.in/products/official-raspberry-pi-5-active-cooler) ₹425; [Robocraze](https://robocraze.com/products/raspberry-pi-active-cooler) ₹529; Thingbits ₹531 (2026-09-16) | Silverline in stock; Robocraze collection availability conflicted | 0–7 d | None without equivalent final-enclosure thermal evidence | 1 | **425–531** | Low–Med | Temperature/CPU/fan logging, microphone-noise capture | Body vent path, dust/service access and acoustic separation from body mics |
| C0 storage — COST-DOWN LEAD | Official Raspberry Pi **32 GB A2** card is the current price/performance lead; SanDisk High Endurance 32 GB is an endurance-only comparison, not a cheaper verified option; official Pi 64 GB is a capacity fallback only if the measured image/log/update budget fails | [ThinkRobotics Pi 32 GB](https://thinkrobotics.com/collections/buy-raspberry-pi-online/products/official-raspberry-pi-32gb-micro-sd-card-a2-class-unprogrammed); [Reliance SanDisk listing](https://www.reliancedigital.in/product/sandisk-32-gb-high-endurance-uhs-i-memory-card-mqkvb8-10198830) | Pi card shown in stock around ₹1,300–1,480; SanDisk retailer listed ₹2,429 on 2026-09-17 but suffix/delivery unverified. Former ₹679 staging-store signal is invalid | Recheck | 64 GB official Pi only on measured capacity failure | 1 Pi lead; comparison only if justified/authorized | **≈1,300–1,480 Pi lead only** | Med — authenticity/endurance/random-I/O trade | Abrupt-power fixture; I/O and image-restore test | Bounded log policy; accessible card service; registered free-space/wear margin |
| **Head motion controller — C2 MODULE SELECTED** | **Waveshare ESP32-S3-Zero**, plain ESP32-S3FH4R2 variant, **headerless** (not `-M`). 4 MB flash / 2 MB PSRAM, 19 exposed GPIO, 23.5 × 18 mm castellated. C1/shared-display control is rejected on SKU 30493's GPIO budget. Selected on pin budget, pocket fit and bus-neutrality; see `control-topology-options.md` §6.3. | [Hubtronics](https://hubtronics.in/esp32-s3-zero) SKU 25081 ₹549 with two in stock; Robosap; Robu; Waveshare direct (2026-09-16; reconfirm) | In stock | 0–3 d | ESP32-S3-DevKitC-1 if head repackaging is accepted; ESP32-S3 SuperMini as rough second source | 1 + 1 spare | **~549 each incl. GST** | Med — single-source Waveshare; two documented fallbacks | Logic analyzer/current logger, scale | Own installed module, mount, connectors and harness in M008 — **weigh the assembly, do not enter a datasheet mass**. Reconfirm price/stock before payment |
| Runtime head IMU | **Not installed for stationary RP-01.** Servo encoders provide joint angle; an IMU is bench-only for backlash/resonance when useful. | — | No purchase | — | — | 0 | 0 | None | Nano/bench instrumentation | Excluded from moving-head mass ledger |
| **Base/drive controller C3 — PROTOTYPE BOARD SELECTED** | **Official Espressif ESP32-S3-DevKitC-1-N8**; owns wheel loops, local hazards, expiry and readiness; same ESP-IDF target family as C2. N8 intentionally preserves GPIO35–37; later WROOM-1-N8 carrier only by controlled equivalence | [Tech Depot India](https://techdepot.in/products/espressif-esp32-s3-devkitc-1-n8-developmnt-board) ₹2,273.70 captured; authorized distributor preferred | Shown in stock with 8–10 d delivery; recheck exact ordering code | 0–14 d | N8R8 only after a frozen pin map proves ≥3 spare safe GPIO and requalification | 1 + spare per repair strategy | **~2,274 captured official-board listing** | Med — exact-board availability and revision | Logic analyzer, current logger, watchdog fixture | Body carrier/backplane waits on RP-03 motor driver/sensors/pin map |
| Base-frame IMU | 6-axis gyro/accelerometer for later chassis heading/attitude, caster/traction disturbance and tip/pickup detection; head mounting is excluded because subtracting measured neck motion would add avoidable calibration and timestamp error | On-hand board if suitable / Robu | Deferred | — | Same family as selected base controller where practical | 0–1 | TBD | Low | — | Rigid base/controller mount; feeds RP-03, not moving-head ballast |
| Internal links — PHYSICAL LAYER SELECTED, SUFFIX OPEN | Framed UART over full-duplex differential RS-422/485 for C0↔C2 and C0↔C3; **THVD1451D SOIC is the prototype lead**, THVD1451 VSON is a qualified-assembly cost option, and Renesas ISL83077EIBZA is a cheaper but less-protected conditional challenger. SN65HVD1474 is the protected fallback; MAX3490E is rejected for cost. C2 relays display state over head-local RS-485. | TI/Renesas via authorized DigiKey/Mouser channels | THVD1451D: 254 at ₹374.26; VSON: 17,712 at ₹222.10 (2026-09-16); Renesas Mouser category snapshot: 5,098 at ₹185.43 (recheck exact-part checkout) | Recheck | SN65HVD1474 after pin/electrical/footprint screen | 2 ends × 2 links + spares; one display transceiver | **Four main endpoints ≈1,497 TI SOIC, ≈742 Renesas IC-only, former MAX ≈3,910** | Med — Renesas has only HBM, not IEC-contact ESD claim; protection/termination, startup/EMI and carrier cost must qualify | Scope, logic analyzer, noise/flex fixture | Pi/C2/C3 carriers, two twisted pairs + common reference per main link |
| External controller watchdog — FAMILY SELECTED | TI TPS3436-Q1 window watchdog per C2/C3, hardware-qualifying READY; exact timing/latch suffix after loop measurement. TPS3430 cost-down rejected: about ₹53/device saving does not repay harder VSON assembly and requalification | TI/Mouser/DigiKey | One TPS3436-Q1 example suffix showed ₹281.40 cut tape; recheck exact suffix | Recheck | TPS3431 timeout-only rejected for final path | 2 + spares | **~₹563 for two as a family price signal only** | Med — suffix/circuit choice | Scope, programmable fault/clock injection | Integrated C2/C3 carriers and motor-gate truth table |
| Motor/servo driver | Drives base motors + head servos, current sense preferred | Robu / Zbotic | Common | 0–3 d | Separate ESC + servo rail | 1–2 | 500–2,000 | Low | Soldering | Wiring harness |

## Head (RP-01 / RP-06)

| Component | Candidate spec | Supplier | Avail. | Lead | Substitute | Qty | Landed ₹ | Replacement risk | Required tools | Fab dependency |
|---|---|---|---|---|---|---:|---:|---|---|---|
| **Face display — SELECTED** | **Waveshare ESP32-S3-LCD-4.3 no-touch, SKU 30493**; 800×480 IPS, integrated ESP32-S3/LVGL renderer, ~106.1×67.8 mm. Exact module is locked; alternatives require recorded hard-failure change control. The no-touch variant remains the cost-down choice; touch adds cost without a V1 requirement. | Hubtronics exact-SKU lead; REES52 lower-price lead pending exact-SKU confirmation | Hubtronics ₹3,065 incl. GST with two units; REES52 ₹2,920 with 20 units on 2026-09-16; reconfirm exact SKU/revision before payment | Domestic shipping estimate to be confirmed | Contingency references only: Waveshare 43H-800480-IPS no-touch DSI SKU 24159; DWIN DMG80480T043_09WN | 1 sample; second only after acceptance | **2,920–3,065 current leads; planning allowance 3,000–4,600** | Med until exact lower listing, actual mass, repeat stock, optical result and sustained animation test close | Current logger, scale, temperature/frame-time logging, smoked-window samples | ~106 × 68 mm hidden body behind a ~94–95 × 53–54 mm optical aperture and ~110–115 × 60–65 mm bezel/window treatment; listed 118 g is not accepted as installed mass until sample is weighed |
| Smoked face window | Acrylic/PC with ~94–95 W × 53–54 H mm optical aperture inside a ~110–115 W × 60–65 H mm bezel/window treatment, hiding display edges | Local acrylic | Common | 0–2 d | Tint film over clear panel | 1 | 200–800 | Low | Cutting | Laser/print fit |
| **Camera — SELECTED** | **Raspberry Pi Camera Module 3 Wide, visible-light/IR-cut, order code SC0874**; IMX708, 11.9 MP, 120° diagonal / 102° horizontal / 67° vertical, autofocus, HDR, 25 × 24 × 12.4 mm, MIPI CSI-2. Exact module is locked; see `camera-candidate-study.md`. | Supplier not locked; ElectroPi and Silverline are current leads | ElectroPi listed 62 units and Silverline listed in stock on 2026-08-29; reconfirm | Domestic dispatch estimate to be confirmed | Contingency only: Arducam B031202 after recorded change control | 1 sample; second only after acceptance | **3,088–3,210 verified listings; planning allowance 3,000–4,500** | Med until actual mass, SBC compatibility, image/latency and moving-interconnect tests close | Camera calibration target, live frame/error/latency logger, axis-conditioned cable endurance fixture, scale | Central lens/LED/display clearance; complete module, mount, connector and three-axis moving-link mass/CoM. Supplied 200 mm FPC is bench-usable only until the H1/H2/H3 evidence in `head-harness-routing-study.md` selects a production interconnect |
| **Status light — WORKING SELECTION 2026-09-26** | **Worldsemi WS2812B-2020-V6** on a 5 × 5 mm carrier (`PCB-11`) behind the crown light pipe, driven by D1 GPIO6 at 3.3 V; 2 kHz PWM ([selection](../02-prototypes/RP-06-cad/peripheral-selection.md) §3). Was: addressable LED beside camera (SCOPE-17) | Elegoo / Robu | On hand | 0 | Single-colour LED + driver | 1+ | 100–500 | Low | Soldering | Optic/diffuser |
| Head actuators (roll/pitch/yaw) | Smart servos/geared motors + feedback screened against Layout 03's nominal **~362/436/509 g roll/pitch/yaw** tree at M008=20 g. **First named paper candidate C01: ROBOTIS XC330-M288-T** (SKU 902-0173-000), 5 V, 23 g, direct 1:1; paper approval OPEN (`actuator-screen-01.md`). Housing mass already matches the Layout 03 tree. Not selected; not purchased. Other families still substitute mass/envelope before screening | Robu / Zbotic / MG Super Labs | Mixed; re-check exact SKU | 0–10 d | Feetech STS class ↔ DYNAMIXEL XL/XC class; XC330-M181-T named as yaw comparison if C01 sag/speed conflict unresolved | 3+ plus one bench sample where needed | 3,000–34,000 | Med–High (exact SKU/cost) | Current/voltage logging, output indicator | 60 mm neck allocation, A0 gimbal centre, direct actuation first |
| Head joint structure | Compact yaw load-bearing shaft/bearing, rising pitch yoke with double ear pivots, and an unresolved display-clear roll support; compare rear spaced-bearing cartridge, annular/perimeter support and displaced roll axis. Ear shells are removable covers, not the structural load path | Local bearing supplier / fabricated parts | Common classes, exact sizes TBD | 0–7 d | Small radial/angular-contact pair ↔ suitable compact supported shaft/ring | set | 500–3,000 | Med until roll load path closes | Printer/machining/measurement | Concept A section blockout; must prove display clearance, overhung moment/deflection, mass and 60 mm fit before CAD freeze |
| **Body microphone array — WORKING SELECTION 2026-09-26** | **4 × Infineon IM73D122V01** on `PCB-06` boards + **2 × ADAU7002** on `PCB-05`, two I²S lanes on the Pi 5 (RP-05 `BD-A04`/`A05`, [selection](../02-prototypes/RP-06-cad/peripheral-selection.md) §2). Was: 4 synchronized PDM MEMS microphones, non-collinear/wide rigid body geometry. **2026-09-14 review note:** a Raspberry Pi cannot capture four PDM channels natively (one I2S port); budget a front end — AC108-class I2S codec HAT (kernel-driver risk on current Pi 5 kernels) or an XMOS-class USB array (driverless, onboard DOA that would also serve CAND-01). Neither selected | Robu | Common | 0–3 d | Alternate synchronized digital MEMS array; USB array ↔ codec HAT | 4 (+ front end) | 800–2,400 mics; front end 2,000–9,000 (`E`) | Med | Soldering | Body PCB/subframe + acoustic ports; none in ears/head; ports away from the SBC cooler exhaust |

## Drive & base (RP-03)

Compare **complete drive sets**, not isolated catalog motors. Neither set is purchased. SKU freeze is closed.

| Component | Candidate spec | Supplier | Avail. | Lead | Substitute | Qty | Landed ₹ | Replacement risk | Required tools | Fab dependency |
|---|---|---|---|---|---|---:|---:|---|---|---|
| **Set A — reference-unit lead, not a freeze** | `D02` JGA25-370-class **6 V 176 RPM 1:35** + 11 PPR Hall + Ø84×21 **4 mm D-hub** wheel + **`D21` Ø1" ball transfer** + printed skid + **two DRV8874** + 2S-class 6.0–8.4 V **direct** `PB-DRIVE-L/R` + printed motor clamp. C3 0.70 m/s clamp **mandatory** (8.4 V no-load 1.08 m/s). P03 HOLD on Oz 900 mA vs NFP ≤3 A. `D20` caster is the comparison swap on the same mount. **2026-09-19 paper** (`RP-03-locomotion/research.md`): encoder 176 RPM suffix **not listed** on Robu/Zbotic (no-encoder 130 RPM or encoder 26 RPM); Ø84×21 4 mm D-hub **not a stock article**; D21 CAD envelope is **1″ POM ~29 mm** vs axle 42 mm — mount needs 0–15 mm shim. Do not CAD 15.9 mm steel casters as D21. **Print hubs/shims/two adapters; buy tread, POM ball, import encoder motor.** Full FDM tyre is not a freeze | Robu / Zbotic / NFP–Aslong import / TI channel | Class common; **exact encoder 176 RPM suffix `U` in India** | 0–5 d class; import if suffix missing | Set B (`D03` 1:45) on the same mount; `D20` caster swap | 2 motors + 2 wheels + 1 ball + 1 skid + 2 DRV8874 | Motors 800–2 400; wheels 150–600; ball 100–500; drivers 400–1 600; mount printed | Med — suffix/encoder magnet/`D` stall conflict; ball dent/jam; wheel-class mismatch | Current/fault logging; shaft-retention check; `S-LAM` dent inspection | 170 mm track; 4 mm D-shaft; HIGH_AFT unfittable; radial shaft support HOLD; **front-support height shim 0–15 mm** |
| **Set B — comparison, not a freeze** | Same as Set A except `D03` JGA25 6 V **133 RPM 1:45**. P02 HOLD (0.585 m/s at 6 V). Same driver/wheel/**ball**/supply/mount | same | same | 0–5 d | Set A | same | same class | Med | same | same |
| Front-support comparison article | Ø25–32 mm swivel caster `D20` on the **interchangeable mount**. Not the V1 target (`dimensional-baseline.md` v1.12). Required RP-03 swap. Typical 30 mm robot caster overall height **~38 mm** vs Ø84 axle **42 mm** — same shim stack as the ball | Local | Common | 0–3 d | — | 1 | 50–400 | Low | Trail/flutter/`BM-07` heading; **trail mm still `U`** | Same front-support pocket; **two hole-pattern adapters** (Pololu 3-hole vs 33×38 plate) |
| Cliff / look-down | GPIO analog/digital reflective IR, **not** I2C-only in the stop path. **S01 TCRT5000 lead** with mandatory dark+glossy trial; QRE1113 comparison; VL53L0X rejected as sole cliff | Robu | Common | 0–3 d | Alternate GPIO look-down | 3+ | 100–800 | Med (surface) | Dark/glossy samples | Three leading contacts: ball-forward, lateral, reverse/skid |
| Forward obstacle (stop path) | Analog triangulation IR on ADC. **S04 GP2Y0A41SK0F lead** (4–30 cm, 16.5 ms cycle `D`); **front-support-mounted** (ball) for 0.50 m/s look-ahead; **HOLD at 0.70 m/s** and **HOLD at 0.50 m/s on 2° downhill** (221 mm `d_stop`). VL53L1X is telemetry only | Robu | Common | 0–5 d | Alternate analog IR 4–30 cm class | 1 | 400–1,500 | Med | — | Must see ≥179 mm at 0.50 m/s from the leading contact, 221 mm downhill |
| Bump | Miniature lever/microswitch bar, direct GPIO. **S06 lead** | Local / Robu | Common | 0–3 d | Alternate NO lever | 1 | 50–300 | Low | — | Last layer, not first |
| **Base-frame IMU — WORKING SELECTION 2026-09-26** | **ICM-42688-P on a `PCB-07` board** screwed to the chassis deck (bare part: Robu ₹314, RS India); bench: any SPI+INT1 breakout, e.g. MIKROE-4237 ([selection](../02-prototypes/RP-06-cad/peripheral-selection.md) §4). Was: 6-axis, rigid base mount, **SPI + interrupt**. **S07 ICM-42688-P SPI lead**; UART-MCU angle modules (e.g. Robu 601N1) are not that article. MPU-6500 fallback only if SPI+INT actually wired. Head mounting excluded | Robu / Zbotic | Common modules; confirm SPI | 0–5 d | Bare SPI breakout vs UART-MCU module (reject UART for stop path) | 1 | 300–1,500 | Med | — | `CA` I/O; BD-03 runtime from Phase B |
| Motion safety / limits | E-stop already in `workbench.md` bench scope. Cutoff-coast vs commanded `BRAKE` are two G01 metrics (`BM-14`) | — | — | — | — | 1 | (see workbench) | Low | — | Motor-rail wiring; release does not restart |

## Audio & power

| Component | Candidate spec | Supplier | Avail. | Lead | Substitute | Qty | Landed ₹ | Replacement risk | Required tools | Fab dependency |
|---|---|---|---|---|---|---:|---:|---|---|---|
| **Speaker + amp — WORKING SELECTION 2026-09-26** | **Visaton K 50 WP 8 Ω** (Ø50 × 18 mm, 48 g; Tanotis India) + **MAX98357A** on `PCB-05` (RP-05 `BD-A06`). Was: body-mounted character voice with useful enclosure cavity | Robu / Lamington Rd | Common | 0–5 d | Different driver size | 1 | 300–1,500 | Low | Soldering | Body enclosure/baffle |
| Battery / cells | Chemistry undecided — ADR-06 (18650 holder vs LiPo pouch); package low and forward of drive axle | Robu / local | Common | 0–5 d | 18650 ↔ LiPo | 1 pack | 500–2,500 | Med (safety) | LiPo bag/charger | Pack + holder must help reach `x_CoM=+25 mm`, `h_CoM=124 mm` |
| Compute converter — `PCD-CVT-01/-02` LEADS, NOT SELECTED | Murata OKL-T/6-W12P-C LGA and OKR-T/6-W12-C SIP comparison; 4.5–14 V in, programmable 5.1 V, 6 A/30 W class. Must pass 6.0 V low-line, Pi load-step/ripple and enclosure thermal evidence | Mouser India / Murata channel | OKL page showed 51 immediately dispatchable 2026-09-16; recheck | Import stock; factory replenishment showed 26 wk | OKL ↔ OKR only after equivalent screen; fixed 5 V Pololu is bench-only | 2 samples after authorization | OKL listed ~581 each before checkout; carrier/passives extra | Med — specialized module and custom PCB | Electronic load, scope, current/temperature logging | Dedicated carrier, trim, thermal copper, Pi power-entry circuit |
| C2/display converters — `PCD-CVT-06/-08` LEADS, NOT SELECTED | TPS630701 fixed-5 V production lead; separate device per branch. Pololu S13V10F5/S13V15F5 are bench-only characterization modules | Mouser/DigiKey; Pololu international | IC route distributable; domestic Pololu stock not accepted | Recheck | TPS630701 custom PCB ↔ Pololu bench modules, not drop-in equivalents | 2+2 after authorization | TBD; no landed assembly estimate yet | Med — QFN/passive/layout work or imported modules | Electronic load, scope, current logger | Separate protected branches and power-good/enable wiring |
| Branch/main protection — `PCD-PRO-01…03` LEADS, NOT SELECTED | TPS25982 high-current e-fuse; TPS25947 low-current reverse-blocking e-fuse; Littelfuse ATOF 287 source-fuse family. Exact suffix/rating remains open | Mouser India / Littelfuse channel | TPS259824ONRGET listing showed 5,331 at ₹404.40 on 2026-09-16; other rows recheck | 0–16 wk depending suffix | Only curve/drop-equivalent alternatives | Samples after schematic freeze | TBD | Med — suffix, holder and coordination risk | Fault fixture, electronic load, scope, thermal/current logging | PDB copper/thermal layout and accessible source fuse holder |
| Motor E-stop/operator — `PCD-EST-01` LEAD, NOT SELECTED | IDEC XW1E-BV402M-R, 40 mm mushroom, 2 NC, direct opening/safety lock; commands a low-energy fail-open motor gate and never carries motor current | IDEC authorized channel | Official SKU verified; India stock/price not verified | TBD | Equivalent IEC 60947-5-5 direct-opening 2NC operator after screen | 1 + spare after authorization | TBD | Med until panel/IP/supplier bound | Contact tester, fault fixture | Accessible 22 mm panel opening, protected low-energy loop |
| Motor-arm power stage — `PCD-EST-02` ENGINEERING LEAD, NOT SELECTED | LTC4368-1 with external back-to-back MOSFETs and shunt; bidirectional current-breaker candidate. Not itself a safety-rated subsystem | Analog Devices channel | Distributor availability to recheck | TBD | DC-rated contactor/relay or equivalent dual-FET controller after regeneration/SOA screen | PCB samples after design review | TBD | High — regeneration, FET SOA, common-cause and discharge behavior | Electronic load/source, scope, thermal/current logging | Custom PDB, hardwired E-stop + arm truth table, discharge path |
| Pack/internal connectors — `PCD-CON-01…03` LEADS, NOT SELECTED | Anderson SBS Mini touch-safe keyed pack disconnect; Micro-Fit 3.0 low-current internal; Micro-Fit+ high-current internal. Exact housing, terminals, contacts, gauge and crimp tools form one assembly decision | DigiKey India / Mouser India / authorized channel | SBS Mini housings listed by DigiKey India; exact assembly stock not yet bound | Recheck all lines together | Connector family substitute must repeat resistance/thermal/anti-mate screen | Development sets after authorization | TBD | Med — contact/terminal substitutions invalidate ratings | Manufacturer crimp tooling or controlled equivalent, pull tester, four-wire meter | Panel/service geometry, strain relief, branch-separated pinout |
| USB-C charge input / charger — `PCD-CHG-01/-02` LEADS, NOT SELECTED | STUSB4500QTR standalone PD sink plus BQ25798 1–4S, 5 A buck-boost NVDC charger/power path; preserves Li-ion/Li-polymer/LiFePO4 envelope. Adapter, pack and charge rate open | Mouser India / manufacturer channels | STUSB4500QTR 10,789 at ₹206.86 and BQ25798RQMR 12,583 at ₹491.06 shown 2026-09-16 | ICs in stock; implementation lead TBD | BQ25792 only after Li-ion chemistry freeze; integrated evaluation board for bench | IC/EVM samples only after authorization | ~698 ICs before passives/PCB/adapter; EVM much higher | High implementation, low IC availability risk | USB-PD analyzer, charger GUI/interface, scope, thermal/current logging | Protected USB-C inlet, dense QFN board, thermistor, restricted charge-mode gating |

## Structure & fasteners

| Component | Candidate spec | Supplier | Avail. | Lead | Substitute | Qty | Landed ₹ | Replacement risk | Required tools | Fab dependency |
|---|---|---|---|---|---|---:|---:|---|---|---|
| Printed polymer stock | PLA/PETG for shells & brackets (material choice deferred) | Local filament | Common | 0–2 d | PLA ↔ PETG ↔ ABS/ASA | as needed | 800–2,500 | Low | 3D printer | Print time |
| Heat-set inserts + screws | M3 inserts for repeated service assembly | Robu / local | Common | 0–3 d | Self-tapping (worse for service) | set | 300–1,000 | Low | Soldering iron tip | Boss design |
| Other bearings / pivots | Base and non-head joints as needed; Concept A head bearings are counted in the dedicated head-joint row above | Robu / local | Common | 0–5 d | Bushings ↔ ball bearings | few | 200–1,000 | Low | — | Joint design |

## First project cost range (CON-TBD-13)

Rolled up from the candidate ranges above (**components only — excludes the `workbench.md` bench tooling of ₹10k–25k**):

| Bound | Estimate |
|---|---:|
| Low (frugal/Feetech-class path, on-hand reuse, selected IPS sample included) | **≈ ₹16,000–20,000** |
| High (premium three-DYNAMIXEL head path, selected IPS display included) | **≈ ₹75,000–80,000** |

This is a **planning envelope to gate procurement decisions**, not a budget commitment. The selected display can now be included from the verified ₹3,065 India lead, with allowance for freight and price movement. Stock and freight still require reconfirmation immediately before purchase.

## Open items

- [ ] Verify local stock/price for the "Now" candidates by walking Lamington Road once (per workbench sourcing note).
- [ ] Confirm Hubtronics physically holds the selected no-touch SKU 30493, obtain one sample and run the geometry/mass/animation/power/window validation before freezing the head CAD.
- [x] Concept B was explicitly waived by the builder before fabrication; Concept A is the RP-01 path. No second mechanism sourcing campaign is required unless change control reopens it.
- [ ] Resolve battery chemistry candidate (ADR-06) before any pack purchase.
- [ ] Attach a verified source + one acceptable substitute to each architecture-critical row (RP06-G05 gate).
- [ ] Promote selected rows into a later `hardware/bom/` roll-up once ADRs close.
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

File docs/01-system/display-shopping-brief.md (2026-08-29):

# Makad IPS Face-Display Shopping Brief

| Field | Value |
|---|---|
| Status | **Procurement brief for locked display SKU** |
| Version | 0.3 |
| Last reviewed | 2026-08-29 |
| Governs | Ecommerce searches, Lamington Road calls/visits and supplier checks for the moving-head face display |

## Buy this exact module

> **Waveshare ESP32-S3-LCD-4.3, no-touch version, SKU 30493** — not the capacitive-touch version and not a 480×272 SPI display.

The module is selected and locked for Makad V1. The remaining shopping task is to verify the exact variant, obtain one genuine unit and document its price, revision and delivery—not to continue comparing screens.

## Exact-SKU verification criteria

| Criterion | Accept | Reject / question |
|---|---|---|
| Panel | **IPS**, full colour, 4.3-inch class | TN when IPS is claimed only in the title; monochrome OLED; character LCD |
| Resolution | **800×480 native** | 480×272 unless deliberately accepted as a visual downgrade; interpolated resolution |
| Active area | About **93–101 W × 52–57 H mm** in landscape | Seller gives only diagonal and no drawing |
| Module body | Prefer **≤107 W × 68 H mm**; up to ~122×74 mm only for a proven smart-display fallback | Dimensions exclude PCB, connector or FPC tail |
| Interface | Best: integrated **ESP32-S3 + LVGL**. Next: 15-pin Pi DSI. UART smart HMI is acceptable. | Raw 40/45-pin RGB without a named controller plan; HDMI for the final moving head |
| Touch | **No touch preferred** | Do not pay weight/cost for touch unless it is the only stocked exact module |
| Brightness | **≥300 nit**, with ≥400 preferred | No brightness figure; marketing terms such as “high brightness” only |
| Frame rate | 50–60 fps target or a demonstrated fluid eye animation | “Fast refresh” without timing/example evidence |
| Colour | 65K is adequate for stylized eyes; 262K/16.7M welcome | Do not trade controller reliability for colour depth the artwork does not need |
| Power | Input voltage and typical/worst consumption stated | “5 V” with no current figure or inaccessible power connector |
| Mass | Actual module mass or permission to weigh sample | Shipping weight presented as installed mass |
| Evidence | Exact manufacturer SKU, invoice, live stock, datasheet/wiki and return/DOA policy | Generic title/photo, substituted revision, marketplace seller cannot identify controller |

## Procurement source and contingency references

| Role | Exact item | Seller evidence checked 2026-08-29 | Action |
|---:|---|---|---|
| **Selected source** | Waveshare ESP32-S3-LCD-4.3 **no touch**, SKU 30493 | [Hubtronics](https://hubtronics.in/development-boards/microcontroller-development-boards/esp32-s3-lcd-4.3): ₹3,065 incl. GST, two shown in stock | Confirm SKU 30493, no-touch, unopened stock and shipping time; obtain one unit after confirmation |
| Contingency only | Waveshare 43H-800480-IPS **no touch**, SKU 24159 | [Zbotic product family](https://zbotic.in/product/waveshare-4-3inch-dsi-display/) around ₹3.3k; exact selected variant/live quantity ambiguous | Do not purchase unless selection change control is triggered by a documented hard failure |
| Contingency only | DWIN DMG80480T043_09WN **no touch** | [RoboticsDNA](https://roboticsdna.in/product/4-3inch-800x480-ips-industrial-hmi-uart-lcd-display-without-touch-2/): ₹4,576.01 incl. GST, shown in stock | Do not purchase unless selection change control is triggered by a documented hard failure |

Stock and price are snapshots, not procurement guarantees. Recheck immediately before payment.

## Questions for an ecommerce seller or Lamington Road shop

1. What is the exact manufacturer and complete part number? Please send a photo of the label.
2. Is it IPS, and is 800×480 the native resolution?
3. Is this the no-touch version? If touch is fitted, what is the total module mass?
4. What are the active-area and complete PCB/module dimensions in landscape?
5. Which controller is included: ESP32-S3, DSI adapter, HDMI board, UART HMI or none?
6. Can it play locally stored animations without streaming HDMI video?
7. What input voltage and current does the complete module require at full brightness?
8. What is the module's actual net weight, excluding box and cable?
9. How many identical units are physically in stock, and can the same revision be supplied later?
10. Is there a datasheet/wiki, pinout, example code and dead-on-arrival replacement policy?

## Red flags

- The listing switches among IPS, TFT, OLED and AMOLED as if they are synonyms.
- “4.3-inch” is the only dimensional information.
- The photo shows a Raspberry Pi DSI connector but the description says generic HDMI or SPI.
- The price changes after selecting the required no-touch/800×480 variant.
- The panel is raw RGB and the seller cannot name a compatible controller board.
- The quoted weight is visibly the packed shipment weight.
- The seller will not confirm the exact suffix or sends a different touch version “as equivalent.”

## Reusable procurement-verification prompt for other agents

```text
Find an India-orderable source for this exact locked display module:

- Waveshare ESP32-S3-LCD-4.3
- no-touch version
- official SKU 30493

Do not recommend alternative screens. Reject the capacitive-touch variant, 480×272 products, raw panels, HDMI modules, and listings that cannot prove the exact manufacturer SKU.

For every source report: seller URL, exact SKU/variant evidence, live-stock timestamp, GST-inclusive price, Mumbai delivery estimate, return/DOA policy, and whether the seller can provide a label photo. Also record any manufacturer-declared revision, net mass, power documentation and official documentation links. Separate verified facts from inference.
```

## Purchase gate

Do not buy several speculative panels. Confirm the exact SKU with the seller, obtain **one** selected-module sample, and run the acceptance test in `display-candidate-study.md`. A second unit is justified only after that sample passes geometry, mass, animation, optical, power and availability checks.

## Change log

| Date | Version | Change |
|---|---|---|
| 2026-08-29 | 0.1 | Created the earlier AMOLED sourcing and RFQ brief. |
| 2026-08-29 | 0.2 | Replaced the AMOLED requirement with an India-focused IPS brief, exact first-purchase candidate, seller questions and reusable search prompt. |
| 2026-08-29 | 0.3 | Converted the brief from comparative sourcing to exact-SKU procurement after the project builder locked Waveshare no-touch SKU 30493. |

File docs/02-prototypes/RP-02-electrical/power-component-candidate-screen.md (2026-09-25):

# RP-02 Power-Component Candidate Screen

| Field | Value |
|---|---|
| Status | **Accepted derived candidate screen v0.1, builder-reviewed 2026-09-16. No power component is selected and no purchase is authorized.** |
| Date | 2026-09-16 (addendum §9.2, 2026-09-24: battery working selection) |
| Scope | Part-2 implementation candidates for conversion, protection, motor isolation/E-stop actuation, connectors, conductors and charging/power path |
| Inputs | `RP02-P2-REG-01`, `RP02-P2-REG-02`, `power-branch-contracts.md` v0.4 and `power-calculation-ledger.md` v0.1 |
| Evidence rule | Manufacturer documentation establishes `D`; distributor stock/price establishes only a dated sourcing snapshot; installed performance remains `W` |
| Excluded | Numeric brownout/restart thresholds and hold-up values (policy is now in `brownout-restart-contract.md` v0.1); exact pack chemistry, S-count and capacity; RP-03 drive hardware; final fuse ratings; purchase |

This screen asks a harder question than “is the headline current high enough?” A candidate survives only when its voltage window, loss, thermal behavior, fault response, reverse-energy behavior, configuration risk, documentation and physical implementation are compatible with the registered branch contract.

## 1. Outcome

The following parts or families are worth carrying into schematic and bench work:

| Function | Lead carried forward | Present disposition |
|---|---|---|
| `PB-COMPUTE` conversion | ADI `LTC3119` buck-boost (`PCD-CVT-10`), TI `TPS55288` fallback; the Murata `OKL-T/6-W12P-C` / `OKR-T/6-W12-C` are on **Hold** (2026-09-24 addendum, §4.1: cannot regulate 5.1 V below about 6.4 V input) | **Lead, conditional** — `LTC3119` regulates through the 2S sag; output current at 5.4 V input, thermal at 3 A and the setpoint margin remain |
| `PB-SAFE-C2` production conversion | TI `TPS630701` fixed 5 V implementation | **Lead, conditional** — enable, power-good and load disconnect are stronger than a three-pin hobby module; requires a custom PCB |
| `PB-SAFE-C2` bench conversion | Pololu `S13V10F5` | **Bench-only lead** — wide-input fixed 5 V and 1 A class, but no enable, power-good or reverse protection |
| `PB-DISPLAY` bench conversion | Pololu `S13V15F5` | **Bench-only lead** — 1.5 A class with margin over the 0.70 A planning peak; same control limitations as above |
| High-current branch protection | TI `TPS25982` family | **Lead, conditional** — 2.7 mΩ typical path and programmable 2–15 A behavior; exact suffix, curve and location remain open |
| Low-current isolation/protection | TI `TPS25947` family | **Lead for C2/display/source ORing; rejected at 5 A compute output** |
| Replaceable source fuse | Littelfuse `ATOF 287` family plus a rating-compatible holder | **Lead family only** — rating waits on measured profiles and fault impedance |
| Physical E-stop operator | IDEC `XW1E-BV402M-R`, 40 mm mushroom, 2 NC | **Lead operator, conditional** — direct-opening/safety-lock evidence exists; it commands the motor switch and does not carry motor current |
| Motor-arm power switch/controller | ADI `LTC4368-1` plus external back-to-back MOSFETs | **Engineering lead, not a safety-rated subsystem** — permits bidirectional-current analysis; FET, shunt, thermal and regeneration proof remain |
| Retained pack disconnect | Anderson `SBS Mini` keyed housing/contact system | **Lead family, conditional** — touch-safe, keyed, high-cycle and ample current class; exact contact, gauge, colour and retention remain |
| Low-current internal connector | Molex `Micro-Fit 3.0` | **Lead for C2/display only** — exact circuit count, terminal and measured loop resistance required |
| High-current internal connector | Molex `Micro-Fit+` | **Lead family, conditional** — stronger current/contact-resistance class than standard Micro-Fit; exact configuration required |
| Charge inlet / PD negotiation | USB-C receptacle plus ST `STUSB4500QTR` | **Architecture lead** — standalone dead-battery PD sink; not a battery charger |
| Charger / NVDC power path | TI `BQ25798` | **Architecture lead** — preserves 1–4S Li-ion/Li-polymer/LiFePO4 admissibility; exact charge settings wait on the pack |

No moving-head power cable is selected. The electrically adequate industrial torsion-cable examples found are too heavy and bulky to assume into the head, while generic silicone wire has no defensible torsion-life specification. That is a real open item, not a sourcing omission.

## 2. Candidate namespace and dispositions

Candidate records use `PCD-<class>-<nn>`:

| Class | Function |
|---|---|
| `CVT` | DC/DC conversion |
| `PRO` | Fuse, e-fuse and branch protection |
| `EST` | E-stop operator and motor-arm switching |
| `CON` | Connector/interconnect |
| `CAB` | Conductor or moving cable |
| `CHG` | Charge inlet, negotiation and charger/power path |

Dispositions are deliberately weaker than selection:

| Disposition | Meaning |
|---|---|
| **Lead** | Best presently documented route into schematic/bench evaluation; not selected |
| **Conditional** | Admissible only if the stated evidence closes |
| **Bench-only** | Useful for characterization but missing an installed-product requirement |
| **Hold** | Potentially admissible, but an upstream decision is absent |
| **Reject** | Fails a current registered contract or lacks minimum engineering evidence for the stated use |

## 3. Screening gates

Every candidate is screened against all applicable gates below. A missing value is not a pass.

| Gate | Required question |
|---|---|
| Source/load window | Does the complete tolerance/temperature window cover the branch, including the historical 6.0–8.4 V 2S sensitivity where applicable? |
| Terminal margin | After converter tolerance, ripple, switches, protection, both contacts and both conductors, is the registered load-terminal envelope retained? |
| Continuous/transient capability | Are current, duration, repetition and thermal derating supported by curves rather than a single headline rating? |
| Fault containment | Is overload/short behavior known, including blanking, foldback, retry, latch, thermal shutdown and restoration? |
| Reverse energy | Can the part tolerate or deliberately block backfeed/regeneration without creating rail overvoltage or an unintended powered domain? |
| Default state | On loss of software, control power or wiring, does the hazardous path become or remain safe? |
| Configuration integrity | Are trim, NVM, firmware and part-suffix choices controlled and verifiable? |
| Physical implementation | Are PCB copper, thermal vias, capacitance/ESR, crimp tooling, strain relief and service geometry achievable? |
| Evidence quality | Is there an official datasheet/product specification with the necessary limits and curves? |
| Sourcing | Is the exact orderable part available from a traceable supplier, with a substitute strategy and no purchase implied? |

## 4. DC/DC converter candidates

### 4.1 `PB-COMPUTE`

The selected Raspberry Pi 5 requires a dedicated 5.1 V nominal branch capable of the 5 A interface case. The [Raspberry Pi 5 USB-PD paper](https://pip-assets.raspberrypi.com/categories/685-app-notes-guides-whitepapers/documents/RP-009856-WP-1-USB%20Power%20delivery%20on%20Raspberry%20Pi%205.pdf) confirms that Pi 5 requests only 5 V profiles, uses the optional 5 V/5 A PDO when present and otherwise assumes 5 V/3 A unless `PSU_MAX_CURRENT=5000` or `usb_max_current_enable=1` deliberately overrides negotiation. Therefore converter capability and Pi power-entry policy are separate decisions.

| ID | Candidate and `D` facts | Screen | Disposition |
|---|---|---|---|
| `PCD-CVT-01` | Murata [`OKL-T/6-W12P-C`](https://pim.murata.com/asset/pim4/nonIsolatedDCDCconverter/OKL-T6-W12_PDF_NONISOLATEDDCDCCONVERTER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): 4.5–14 V input, 0.591–5.5 V programmable output, 6 A/30 W, 20 mV p-p maximum listed ripple/noise, 91% minimum/93% typical efficiency at 12 V→5 V full load, positive enable | Fits 5.1 V and the historical 2S window. LGA module demands a custom carrier, output-trim tolerance control, specified capacitors and thermal layout. Must prove 6.0 V input, 5.1 V output, Pi workload/full-interface steps and enclosure temperature | **Lead, conditional** |
| `PCD-CVT-02` | Murata [`OKR-T/6-W12-C`](https://pim.murata.com/asset/pim4/nonIsolatedDCDCconverter/OKR-T6-W12_PDF_NONISOLATEDDCDCCONVERTER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): 4.5–14 V input, 0.591–6 V programmable output, 6 A/30 W, through-hole SIP | Electrically comparable and easier to rework on a prototype distribution board. Larger and less mechanically compact; the same low-line, output-capacitance and thermal tests apply | **Lead comparison, conditional** |
| `PCD-CVT-03` | Pololu [`D42V55F5`](https://www.pololu.com/product/5571): fixed 5 V; catalogued 6 A typical maximum is specified at 42 V input and the input-dependent graph governs | Practical prebuilt module, but it does not implement the registered 5.1 V converter target and low-line dropout/thermal behavior must be read at 6.0 V. It may characterize a restricted 3 A Pi configuration only if the power-entry policy is recorded | **Bench-only** |
| `PCD-CVT-04` | Pololu [`D42V55F5.3`](https://www.pololu.com/product/5572/specs): fixed 5.3 V nominal, 6 A class | Its ±3% output family tolerance can reach about 5.46 V before transient/ripple. No official Pi input-maximum proof was found that makes this safe | **Reject for direct Pi power** |
| `PCD-CVT-05` | Murata [`MYLSM00502ERPL`](https://www.murata.com/products/productdata/8807034880030/MYLSM00502ERPL.pdf): 4.5–17 V input, programmable through 5.25 V, 2.5 A output | Cannot satisfy the registered 5 A-capable interface | **Reject for `PB-COMPUTE`** |
| `PCD-CVT-10` | ADI [`LTC3119`](https://www.analog.com/media/en/technical-documentation/data-sheets/3119fb.pdf) (datasheet 3119fb read 2026-09-24): 2.5–18 V input, 0.8–18 V output, 5 A in buck mode for Vin > 6 V and 3 A at Vin = 3.6 V for 5 V out, four 30 mΩ switches, 7–8 A inductor limit, RUN-pin enable with programmable UVLO, PGOOD, zero-current detection (does not sink), 28-lead QFN or TSSOP | Regulates through the 2S sag; hardware-only enable and analog configuration. No hiccup or latch, no adjustable current limit, no regeneration sink. Output current at 5.4 V input is not stated (about 4.5 A by linear interpolation, `E`); continuous use above about 3 A is thermally limited | **Lead for `PB-COMPUTE` and `PB-HEAD`, conditional** (`board-specs.md` `BD-05`) |
| `PCD-CVT-11` | TI [`TPS55288`](https://www.ti.com/product/TPS55288) (datasheet SLVSF01B read 2026-09-24): 2.7–36 V input, 0.8–22 V output, boost-side switches 7.1 / 7.6 mΩ, programmable output limit to 6.35 A, output-current monitor, FPWM lets the inductor current reverse, hiccup default on, VQFN-HR 4.0 × 3.5 mm | Lower loss and a programmable limit, but the output stays off until an I2C write sets `OE`, the OVP is 22.5–24.5 V, and the sink magnitude is unspecified | **Fallback**, conditional |

**Addendum 2026-09-24 (`D`, Murata OKL-T/6-W12/W5 datasheet, "Voltage Range Graph": the limits "apply at all output currents").** The lower input limit for a 5.0–5.1 V output is about 6.3–6.4 V (graph read, ±0.2 V), so `PCD-CVT-01` and, by the same family, `PCD-CVT-02` cannot regulate from the 6.0 V low line this screen requires evidence at, and cannot from the 5.4–5.7 V near-empty sag in the ledger §5.3. The datasheet's own low-line row (6.2 V in, 5 V out, 6 A → 4.54 A) implies 30 W out from 28 W in and conflicts with its graph; settle it at the bench. The outputs are also "not intended to sink appreciable reverse current" and the module hiccup-retries on a short. Disposition: **demoted from "Lead, conditional" to "Hold"**, in favour of `PCD-CVT-10` (`LTC3119`) for `PB-COMPUTE` and `PB-HEAD`, with `PCD-CVT-11` as fallback (`board-specs.md` §5.4.2). Not a registered change.

`PCD-CVT-01` and `-02` satisfy the existing “two candidates minimum” requirement. `PCD-CVT-03` is not counted as an equivalent installed candidate because it changes the registered output and Pi power-entry assumptions.
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

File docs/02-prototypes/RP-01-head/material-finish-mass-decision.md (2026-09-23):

# RP-01 Head Material, Finish and Mass Model — Decision Record

| Field | Value |
|---|---|
| Status | **RP-01 build decisions locked; system baseline revised; measured mass remains open** |
| Date / revised | 2026-08-31 / 2026-09-12 |
| Scope | Head shell material, finish system, display-envelope fit and revised mass model |
| Supersedes for RP-01 | `../../01-system/dimensional-baseline.md` head mass target of approximately 250 g and any RP-01 load/actuator conclusion derived from it |
| RP-01 effect | The system-level `~250 g` head target is obsolete. This record's historical `~490 g` build-up is a pre-M008 spreadsheet model; current Layout 03 is nominally ~509 g complete at M008=20 g E, with M008 still unweighed and candidate servo substitution required |
| Feeds | `payload-mass-capture.md`, CAD blockout, `physics.md`, `rig.md`, `gates.md`, actuator selection |

## 1. Locked RP-01 decisions

| ID | Decision | Rationale / boundary |
|---|---|---|
| D-01 | **Print all RP-01 structure and skin parts in PLA.** | Best sanding/filler behaviour, low iteration cost, high dimensional accuracy and no enclosure requirement. |
| D-02 | PLA is an **RP-01 build decision, not the final Makad material decision**. | Creep and thermal risk remain open. |
| D-03 | Mark structural mass rows M010–M012 as **provisional PLA** pending RP-01 thermal and creep evidence. | A later PETG/ASA structural reprint is then a recorded material change, not an unexplained mass discrepancy. |
| D-04 | Use **real M2 button-head screws** for visible industrial-design fasteners. | Metal should read as metal; planning mass is approximately 0.35 g each until the actual kit is weighed. |
| D-05 | Apply the complete nine-step finish system in §5. | The chipped-over-dark-substrate finish is central to the chosen visual read. |
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

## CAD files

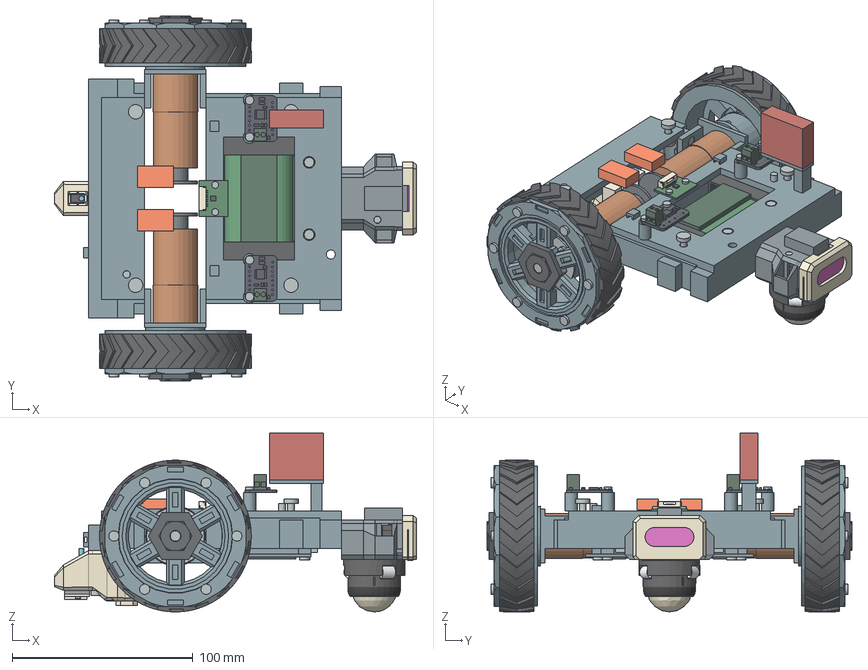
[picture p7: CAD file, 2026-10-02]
docs/03-build/01-chassis/v1/cad/chassis-v1.step
200.5 x 202.0 x 99.0 mm
CHASSIS_FRAME_FRONT_MODULE
CHASSIS_FRAME_REAR_MODULE
REAR_KEEL_HEATSET_INSERT_1
REAR_KEEL_HEATSET_INSERT_2
REAR_KEEL_HEATSET_INSERT_3
REAR_KEEL_HEATSET_INSERT_4
BATTERY_TUB_BOTTOM_HATCH
BALLAST_STEEL_BAR
BALLAST_M3_CSK_HEAD_L
BALLAST_M3_SHANK_L
BALLAST_M3_CSK_HEAD_R
BALLAST_M3_SHANK_R
J11A_HATCH_SCREW_M3X6_1
J11A_BOSS_INSERT_M3_1
J11A_HATCH_SCREW_M3X6_2
J11A_BOSS_INSERT_M3_2
J11A_HATCH_SCREW_M3X6_3
J11A_BOSS_INSERT_M3_3
J11A_HATCH_SCREW_M3X6_4
J11A_BOSS_INSERT_M3_4
PACK_STRAP_HOOK_LOOP_L
PACK_STRAP_HOOK_LOOP_R
PACK_FOAM_PAD_L
PACK_FOAM_PAD_R
DRIVER_POST_INSERT_M25_1
DRIVER_SCREW_M25X6_1
DRIVER_POST_INSERT_M25_2
DRIVER_SCREW_M25X6_2
DRIVER_POST_INSERT_M25_3
DRIVER_SCREW_M25X6_3
DRIVER_POST_INSERT_M25_4
DRIVER_SCREW_M25X6_4
AXLE_MOTOR_CARRIER_L
AXLE_BEARING_HOUSING_L
AXLE_BEARING_CAP_L
AXLE_CAP_SCREW_M3X18_L_1
AXLE_PLATE_INSERT_M3_L_1
AXLE_CAP_SCREW_M3X18_L_2
AXLE_PLATE_INSERT_M3_L_2
AXLE_CAP_SCREW_M3X18_L_3
AXLE_PLATE_INSERT_M3_L_3
AXLE_CAP_SCREW_M3X18_L_4
AXLE_PLATE_INSERT_M3_L_4
J04_RAIL_INSERT_M3_L_FRONT_38
J04_CARRIER_SCREW_M3X8_L_FRONT_38
J04_RAIL_INSERT_M3_L_FRONT_48
J04_CARRIER_SCREW_M3X8_L_FRONT_48
J04_RAIL_INSERT_M3_L_REAR_38
J04_CARRIER_SCREW_M3X8_L_REAR_38
J04_RAIL_INSERT_M3_L_REAR_48
J04_CARRIER_SCREW_M3X8_L_REAR_48
AXLE_MOTOR_SCREW_M3X6_L_1
AXLE_MOTOR_SCREW_M3X6_L_2
AXLE_MOTOR_CARRIER_R
AXLE_BEARING_HOUSING_R
AXLE_BEARING_CAP_R
AXLE_CAP_SCREW_M3X18_R_1
AXLE_PLATE_INSERT_M3_R_1
AXLE_CAP_SCREW_M3X18_R_2
AXLE_PLATE_INSERT_M3_R_2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

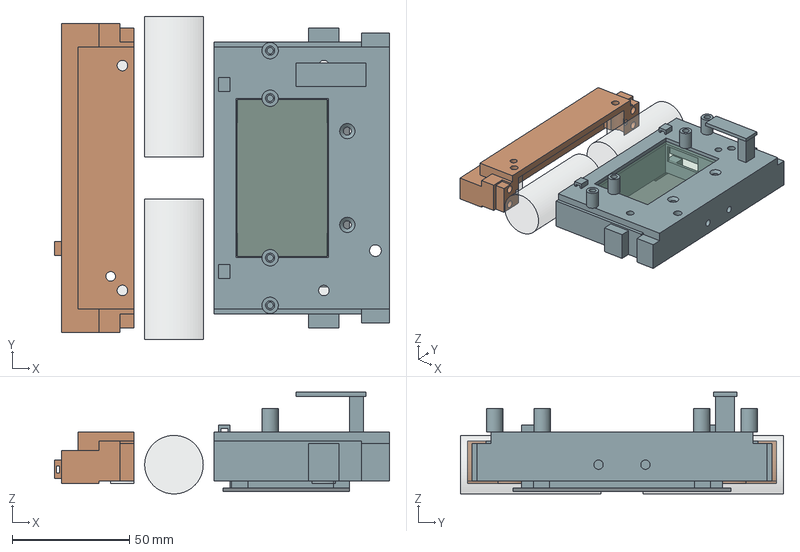
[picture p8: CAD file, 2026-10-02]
docs/03-build/01-chassis/v1/cad/frame-split/frame-split.step
143.0 x 138.0 x 43.5 mm
FS_FRAME_REAR_MODULE
FS_FRAME_FRONT_MODULE
FS_BATTERY_HATCH_FOUR_M3
REFERENCE_ONLY_MOTOR_L_ENVELOPE
REFERENCE_ONLY_MOTOR_R_ENVELOPE
REFERENCE_ONLY_BATTERY_ENVELOPE
REFERENCE_ONLY_BODY_M4_SOCKET_PATH_1
REFERENCE_ONLY_BODY_M4_SOCKET_PATH_2
REFERENCE_ONLY_BODY_M4_SOCKET_PATH_3
REFERENCE_ONLY_BODY_M4_SOCKET_PATH_4

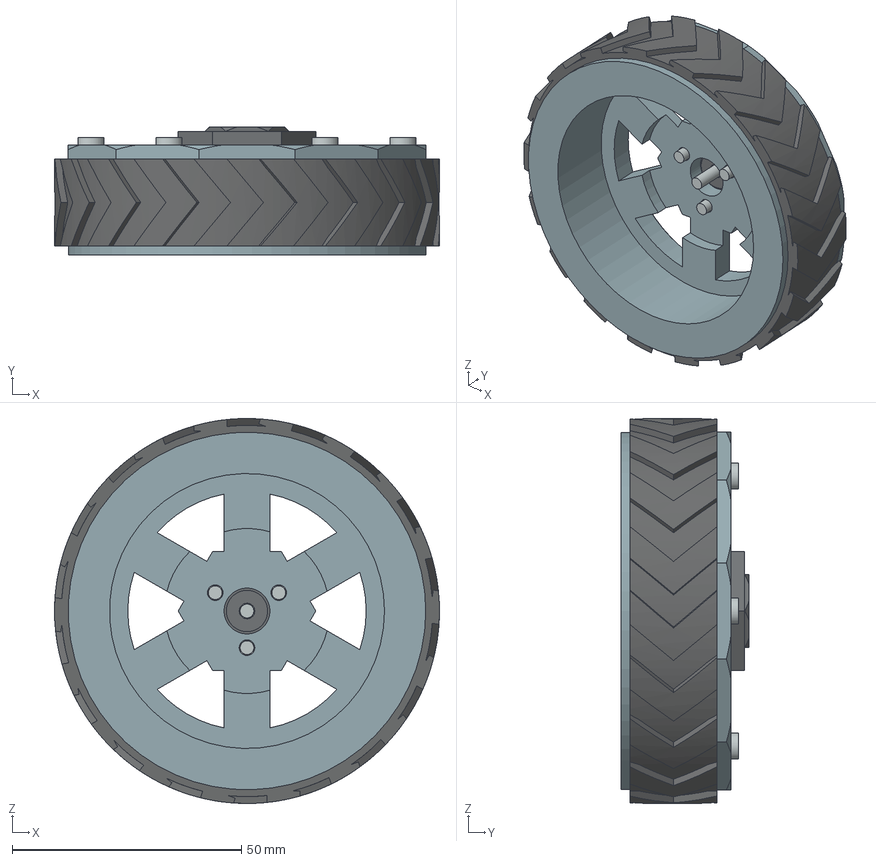
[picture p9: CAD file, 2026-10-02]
docs/03-build/01-chassis/v1/cad/wheel/wheel.step
84.0 x 28.0 x 84.0 mm
WHEEL_RIM_PETG
WHEEL_CLAMP_RING_PETG
WHEEL_HUB_CAP_PETG
WHEEL_TYRE_TPU95A_L
WHEEL_RING_SCREW_M3X8_1
WHEEL_RING_INSERT_M3_1
WHEEL_RING_SCREW_M3X8_2
WHEEL_RING_INSERT_M3_2
WHEEL_RING_SCREW_M3X8_3
WHEEL_RING_INSERT_M3_3
WHEEL_RING_SCREW_M3X8_4
WHEEL_RING_INSERT_M3_4
WHEEL_RING_SCREW_M3X8_5
WHEEL_RING_INSERT_M3_5
WHEEL_RING_SCREW_M3X8_6
WHEEL_RING_INSERT_M3_6
WHEEL_CAP_SCREW_M3X10
WHEEL_SCREW_M3X6_1
WHEEL_SCREW_M3X6_2
WHEEL_SCREW_M3X6_3

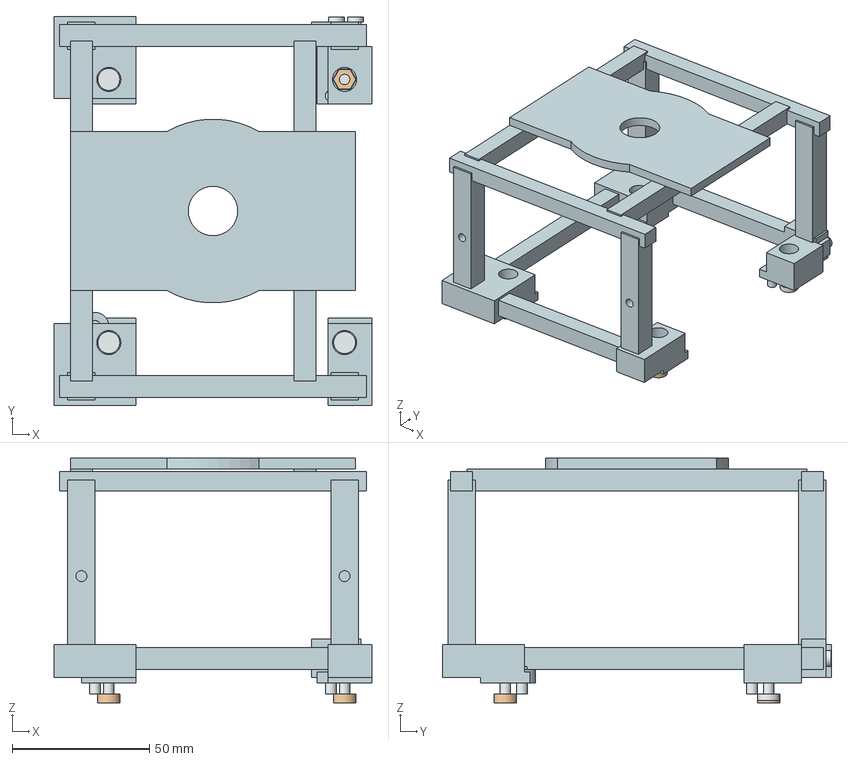
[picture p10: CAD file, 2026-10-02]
docs/03-build/02-body/v1/cad/body-frame-v1.step
116.0 x 142.0 x 89.2 mm
BODY_FRAME_MAIN_PRINT
BODY_FRAME_FRONT_LEFT_FOOT_CASSETTE
BODY_CHASSIS_M4_SHANK_3 x 3
BODY_CHASSIS_M4_HEAD_3 x 3
BODY_CHASSIS_M4_NUT_3 x 3
BODY_CHASSIS_M4_SHANK_4
BODY_CHASSIS_M4_HEAD_4
BODY_CHASSIS_M4_NUT_4
BODY_CHASSIS_LOCATING_PIN_2 x 2
BODY_CASSETTE_INSERT_M3_1
BODY_CASSETTE_SCREW_M3X16_1
BODY_CASSETTE_INSERT_M3_2
BODY_CASSETTE_SCREW_M3X16_2

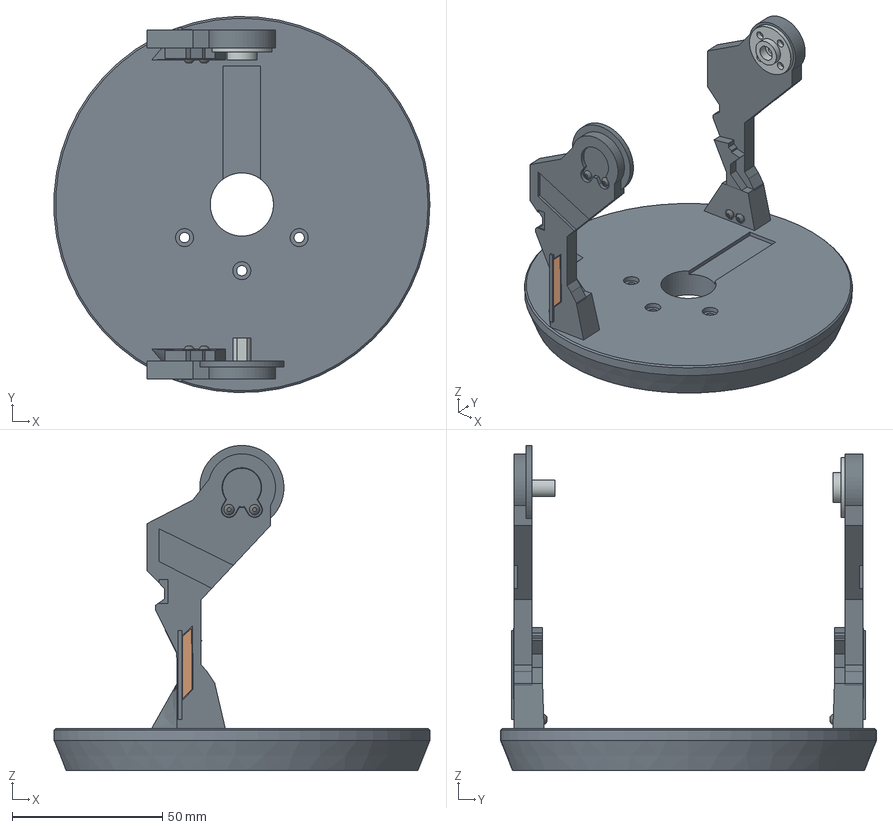
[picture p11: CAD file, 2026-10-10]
docs/03-build/03-head/v1/cad/yaw-yoke.step
124.9 x 124.9 x 108.0 mm
yaw_turntable_disc_flush
yaw_yoke_leg_-55
yaw_yoke_leg_55
yaw_yoke_spine_inlay_-55
yaw_yoke_spine_inlay_55
pitch_trunnion_D6x12_pin
pitch_trunnion_bearing_MR106ZZ
pitch_trunnion_retainer
pitch_horn_25T_disc
pitch_trunnion_retainer_M2x4_240
pitch_trunnion_retainer_M2x4_300
yaw_leg_to_disc_M2x6_55_-17.5
yaw_leg_to_disc_M2x6_55_-12.5
yaw_leg_to_disc_M2x6_-55_-17.5
yaw_leg_to_disc_M2x6_-55_-12.5

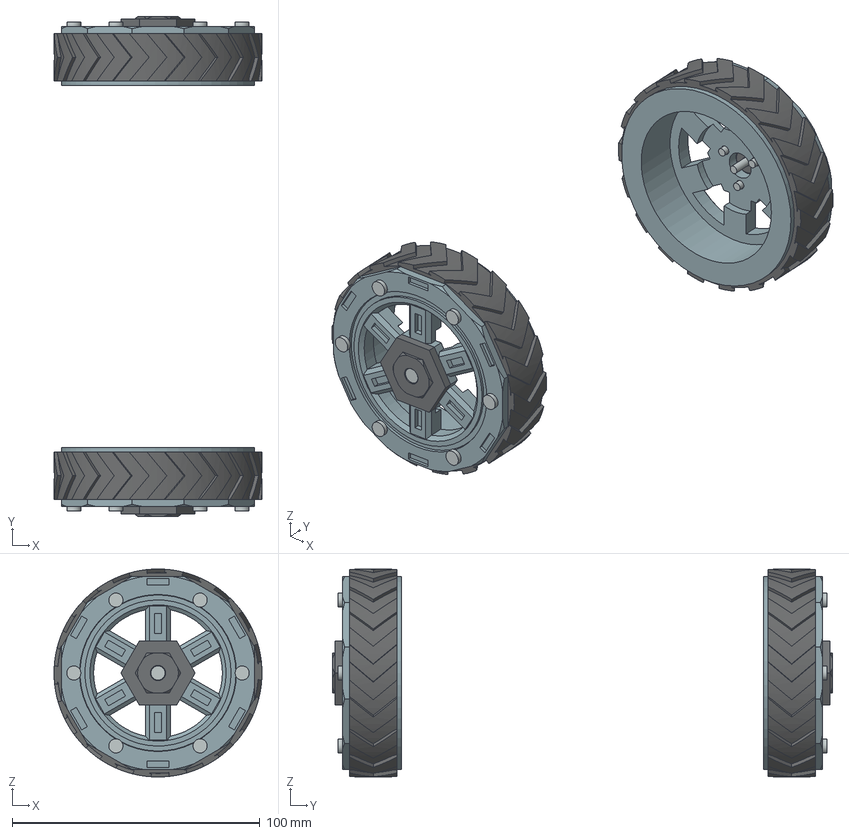
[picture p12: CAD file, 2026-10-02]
docs/03-build/01-chassis/v1/cad/wheel/wheel-pair.step
84.0 x 202.0 x 84.0 mm
WHEEL_L_RIM_PETG
WHEEL_L_CLAMP_RING_PETG
WHEEL_L_HUB_CAP_PETG
WHEEL_L_TYRE_TPU95A_L
WHEEL_L_RING_SCREW_M3X8_1
WHEEL_L_RING_INSERT_M3_1
WHEEL_L_RING_SCREW_M3X8_2
WHEEL_L_RING_INSERT_M3_2
WHEEL_L_RING_SCREW_M3X8_3
WHEEL_L_RING_INSERT_M3_3
WHEEL_L_RING_SCREW_M3X8_4
WHEEL_L_RING_INSERT_M3_4
WHEEL_L_RING_SCREW_M3X8_5
WHEEL_L_RING_INSERT_M3_5
WHEEL_L_RING_SCREW_M3X8_6
WHEEL_L_RING_INSERT_M3_6
WHEEL_L_CAP_SCREW_M3X10
WHEEL_L_SCREW_M3X6_1
WHEEL_L_SCREW_M3X6_2
WHEEL_L_SCREW_M3X6_3
WHEEL_R_RIM_PETG
WHEEL_R_CLAMP_RING_PETG
WHEEL_R_HUB_CAP_PETG
WHEEL_R_TYRE_TPU95A_R
WHEEL_R_RING_SCREW_M3X8_1
WHEEL_R_RING_INSERT_M3_1
WHEEL_R_RING_SCREW_M3X8_2
WHEEL_R_RING_INSERT_M3_2
WHEEL_R_RING_SCREW_M3X8_3
WHEEL_R_RING_INSERT_M3_3
WHEEL_R_RING_SCREW_M3X8_4
WHEEL_R_RING_INSERT_M3_4
WHEEL_R_RING_SCREW_M3X8_5
WHEEL_R_RING_INSERT_M3_5
WHEEL_R_RING_SCREW_M3X8_6
WHEEL_R_RING_INSERT_M3_6
WHEEL_R_CAP_SCREW_M3X10
WHEEL_R_SCREW_M3X6_1
WHEEL_R_SCREW_M3X6_2
WHEEL_R_SCREW_M3X6_3

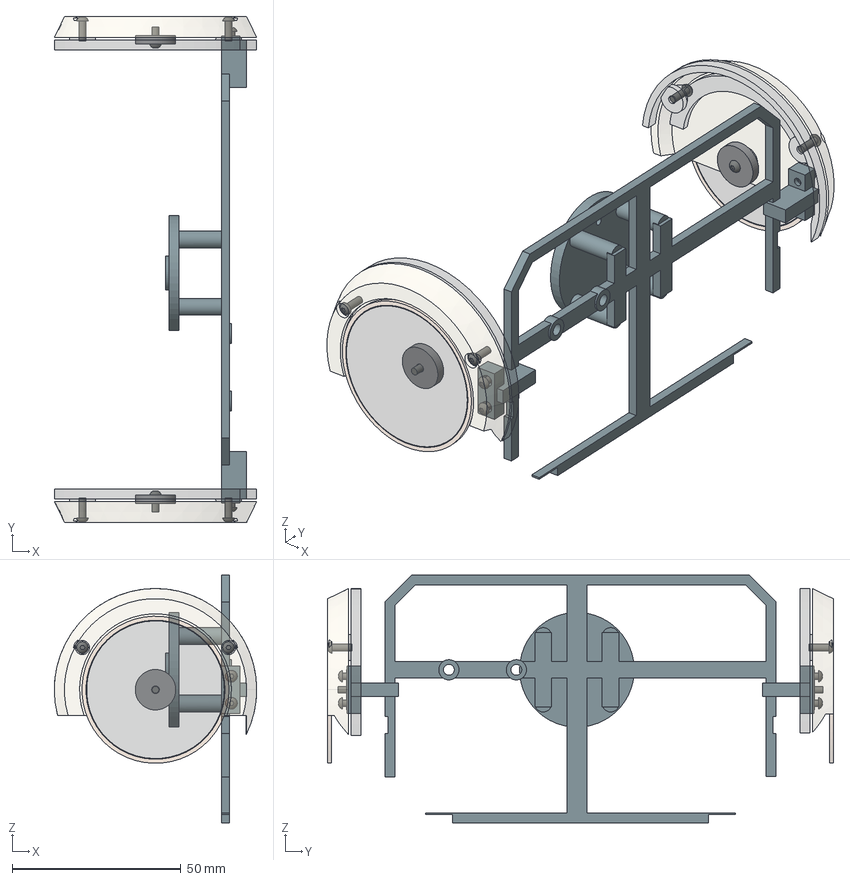
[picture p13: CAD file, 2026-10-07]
docs/03-build/03-head/v1/cad/ears-v1.step
60.0 x 150.0 x 73.5 mm
ear_-1_M2_1
ear_-1_M2_2
ear_-1_hidden_mount_M2_-4
ear_-1_hidden_mount_M2_4
ear_-1_ridged_inner_mount
ear_-1_hollow_removable_cap
ear_-1_amber_inlay
ear_-1_dark_centre
ear_-1_trim_slug_stack_max
ear_-1_trim_M2x5
ear_1_M2_1
ear_1_M2_2
ear_1_hidden_mount_M2_-4
ear_1_hidden_mount_M2_4
ear_1_ridged_inner_mount
ear_1_hollow_removable_cap
ear_1_amber_inlay
ear_1_dark_centre
ear_1_trim_slug_stack_max
ear_1_trim_M2x5
connected_rolling_cradle_flange_ear_stalks

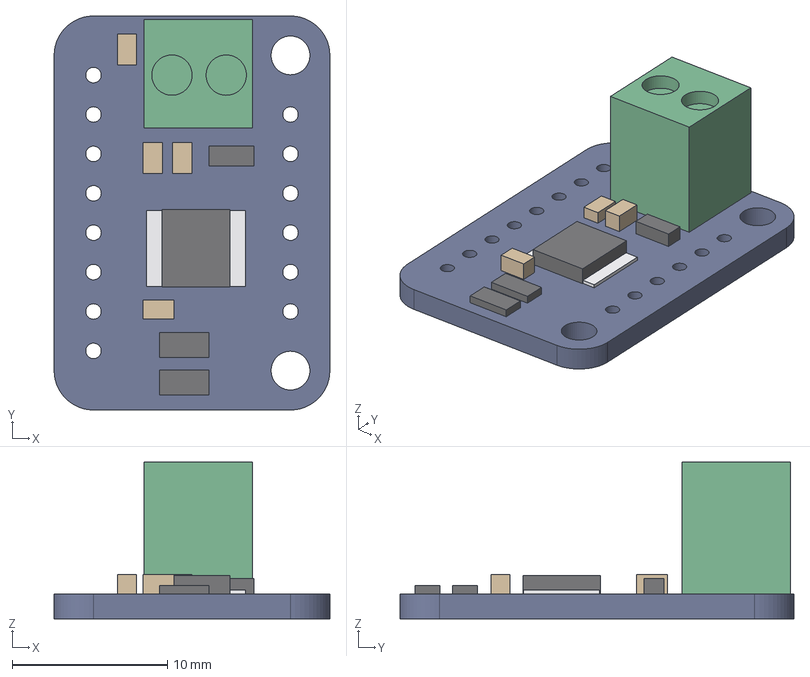
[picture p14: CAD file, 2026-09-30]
docs/03-build/01-chassis/v1/cad/purchased/adafruit_3297_drv8833.step
17.8 x 25.4 x 10.1 mm
ADAFRUIT_3297_PCB
U1_DRV8833PWP_HTSSOP16
U1_LEADS_A
U1_LEADS_B
R1_0R2_1206
R2_0R2_1206
C1_0805
C2_0805
C3_0805
C4_0805
Q1_DMG3415U_SOT23
J1_VMOTOR_TERMINAL_BLOCK_3P5MM

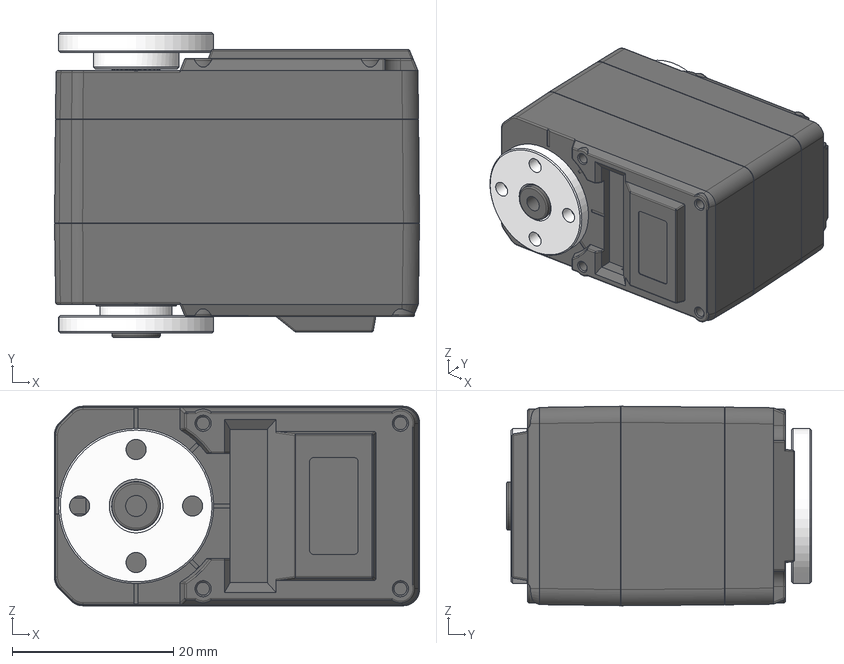
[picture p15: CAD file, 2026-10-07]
docs/03-build/02-body/v1/cad/purchased/waveshare_feetech_st3215_hs_servo.step
45.2 x 37.8 x 24.7 mm
ZK_122
SG-ZIJI_15
XG-ZIJI_16
MOTOR-1723_3
PCB-CHAZUO_92
GE_27
金属舵盘（驱动）
金属舵盘（从动）

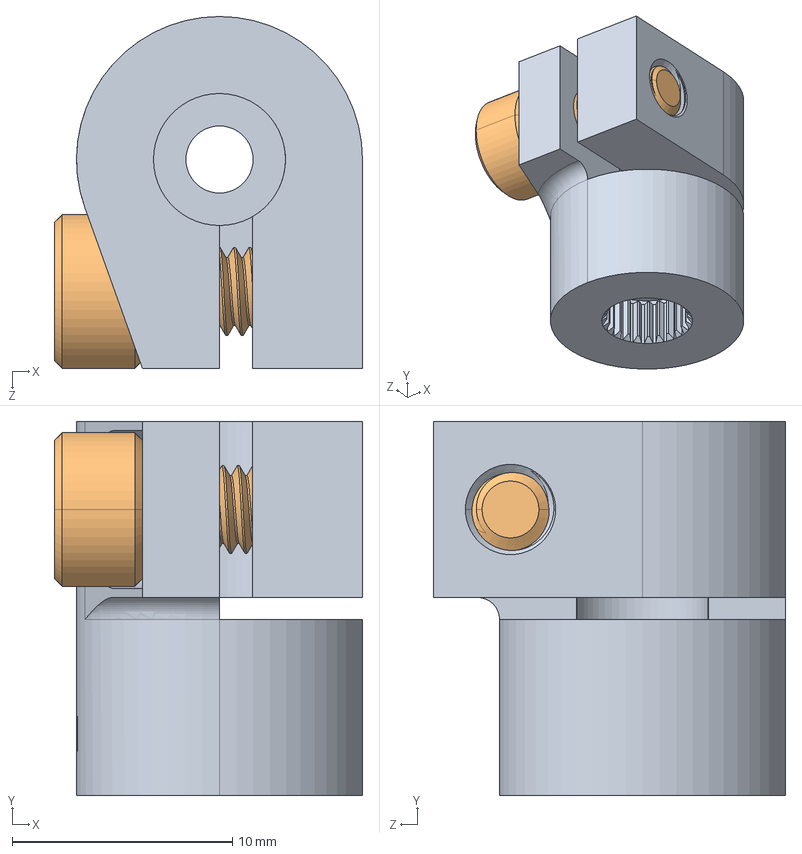
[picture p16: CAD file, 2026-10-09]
docs/03-build/03-head/v1/cad/purchased/gobilda_4001-0025-0006.step
14.0 x 17.0 x 16.0 mm
2800-0004-0010_90128A207

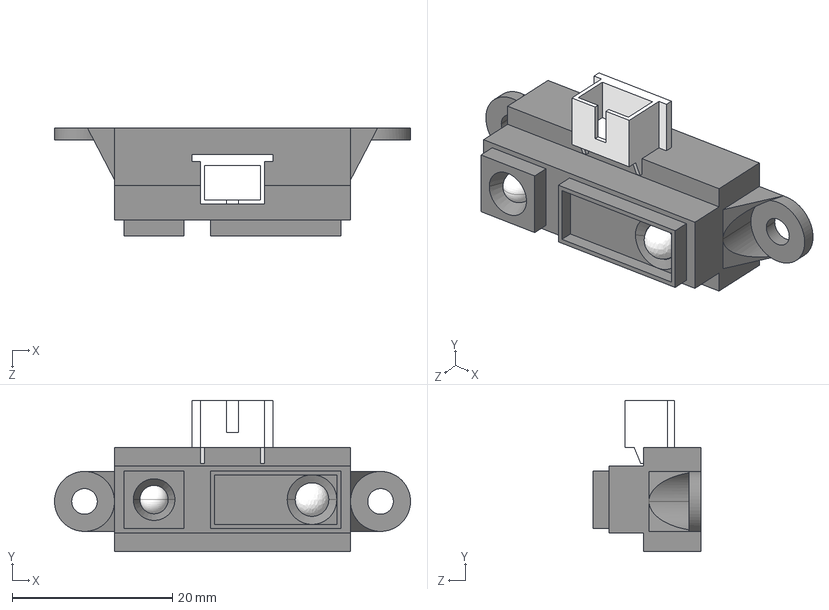
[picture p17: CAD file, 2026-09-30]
docs/03-build/01-chassis/v1/cad/purchased/sharp_gp2y0a21yk0f.step
44.5 x 18.9 x 13.5 mm

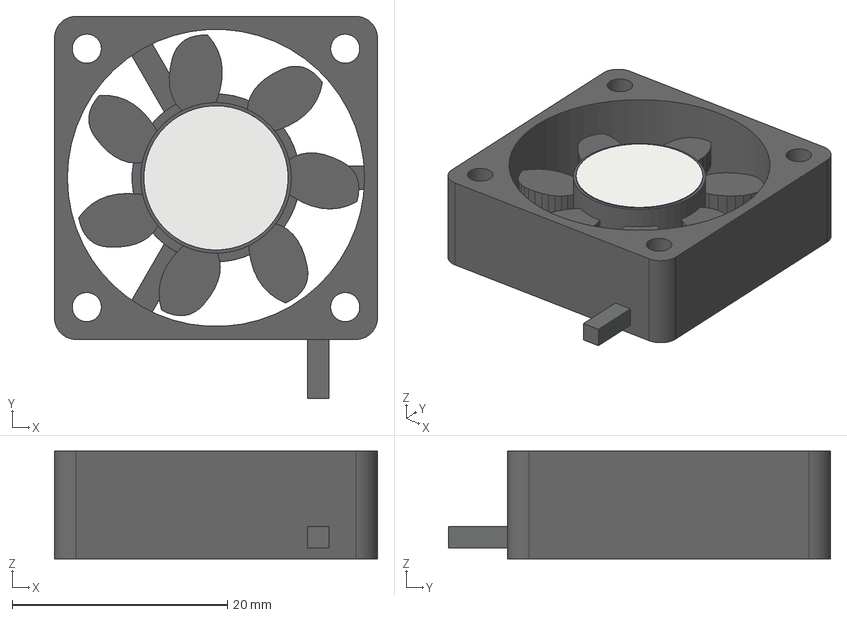
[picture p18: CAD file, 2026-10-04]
docs/03-build/02-body/v1/cad/purchased/dc5v_3010_hydraulic_usb_fan.step
30.0 x 35.5 x 10.0 mm
black_30mm_frame_four_mounting_holes
rear_three_spoke_motor_support
rotor_hub
curved_rotor_blade_1
curved_rotor_blade_2
curved_rotor_blade_3
curved_rotor_blade_4
curved_rotor_blade_5
curved_rotor_blade_6
curved_rotor_blade_7
hub_label_disk
two_wire_exit_stub

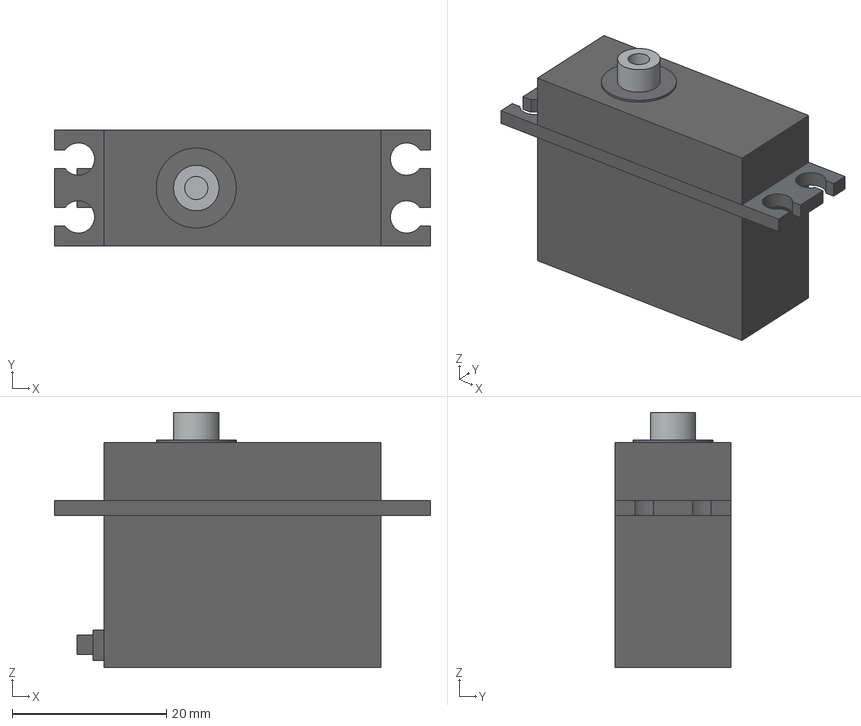
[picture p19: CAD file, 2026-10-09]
docs/03-build/03-head/v1/cad/purchased/sts3045m_reference.step
48.8 x 15.0 x 33.1 mm
D_36x15x29p2_case
D_48p8_mount_span_four_open_D4p2_slots
D_D5p9_25T_spline_envelope_M3_pilot
S_D10p4_output_boss
S_shaft_end_cable_exit

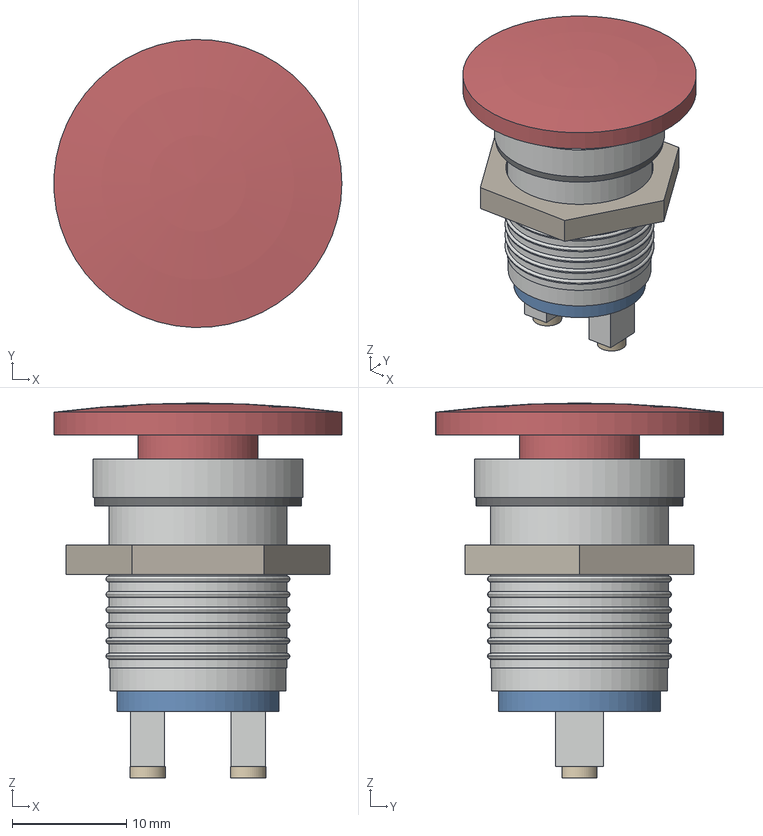
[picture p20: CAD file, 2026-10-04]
docs/03-build/02-body/v1/cad/purchased/sparkfun_com_31041_mushroom_red.step
25.2 x 25.2 x 32.8 mm
red_mushroom_head
red_actuator_stem
front_chrome_bezel
m16_nominal_threaded_barrel
front_rubber_gasket
hex_locknut_20_af_estimated
rear_chrome_shell
blue_switch_insulator
left_screw_terminal_lug
left_terminal_screw_head
right_screw_terminal_lug
right_terminal_screw_head

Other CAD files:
docs/03-build/03-head/v1/cad/purchased/waveshare_esp32_s3_zero_v2.step
docs/03-build/02-body/v1/cad/purchased/infineon_pg_llga_5_4.stp
docs/03-build/03-head/v1/cad/purchased/xc330.stp

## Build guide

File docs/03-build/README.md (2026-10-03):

# 03 — Build

Turn the [prototype decisions](../02-prototypes/) into parts that can be printed, assembled, measured, and revised. This phase is complete when the built robot passes its integration tests, not when the CAD looks finished.

## Governing context

**From 2026-09-28, `03-build/` governs.** Record every new decision, part selection, BOM change, and CAD edit here, in the subsystem and version folder it belongs to. For example, chassis CAD belongs in [`01-chassis/v1/cad/`](01-chassis/v1/cad/) and chassis part choices belong in [`01-chassis/v1/`](01-chassis/v1/) and [`BOM.csv`](BOM.csv). Log every such decision or change as an entry in the central ledger, [`decisions.md`](decisions.md).

[`02-prototypes/`](../02-prototypes/) and its RP folders, including RP-03 locomotion and RP-06 CAD, are **read-only reference**. Link to them for earlier research, gates, and evidence. Do not add decisions to them or edit their CAD. Where an RP document disagrees with `03-build/`, `03-build/` wins.

Before detailing chassis v1, check and freeze the whole-robot spatial baseline: envelopes, datums, key clearances, mass/centre-of-mass assumptions, and subsystem interfaces. Fabrication details remain revisable.

The [project BOM](BOM.csv) is the single parts register. The [chassis v1 BOM](01-chassis/v1/BOM.md) is its dated working snapshot for one chassis; it is not yet a fabrication release.

In the register, `DESIGN` means custom geometry exists, `CANDIDATE` means a part or family is proposed, `SELECTED` means the build choice is settled with receiving and physical verification still separate, `OPEN` means the design needs a choice before release, and `HOLD` means do not order or fabricate until its blocker is resolved. `supplier_candidate` is a lead to verify, not a stock claim. Update `procurement` and `received_measurements` with order and caliper evidence; do not infer receipt from CAD or an old availability check. Refresh a version snapshot deliberately after a BOM change.

## Build order

1. [Chassis and locomotion](01-chassis/) — wheels, drive, supports, and the body mounting interface. Test it with representative body and head mass and centre of mass.
2. [Body](02-body/) — load-bearing frame, packaging, power and wiring, access, cooling, and the head support. Recheck its effect on the chassis.
3. [Head](03-head/) — build and test the mechanism on its real body support. Part selection and isolated joint tests can start earlier.
4. [Full droid](fulldroid/) — assemble the subsystems and rerun whole-robot motion, power, thermal, fault, and interaction tests.

Connectors, cables, pinouts and service breaks are in [05-harness](05-harness/README.md).

Custom schematic, layout and board validation work has a separate [04-pcbs work area](04-pcbs/README.md), which also holds the build deltas to the RP-02 power-board specs. Its unreleased assemblies do not universally block isolated chassis fit or controlled external-supply tests.

Work can overlap. Freeze only the interfaces needed for the next release; record changes that affect another subsystem. The integrated [Layout 02 CAD](../02-prototypes/RP-06-cad/body-chassis/layout-02/) is the starting geometry, not a fabrication release or physical proof.

## What a version means

`v1`, `v2`, `v3`, and later folders are **build iterations**. Each version aims to produce a **print-ready build release** for its defined scope, followed by a physical build and test. A version is not called production-ready before its printed article passes its tests.

Each release needs only these records:

1. **Scope and interfaces** — parts included, assumed loads and mass, dimensions that other subsystems depend on, and known exclusions.
2. **BOM and procurement** — exact purchased parts, quantities, sources, status, and measured dimensions. Keep one project BOM; capture the version's exact BOM as a release snapshot so subsystem lists cannot silently diverge.
3. **Fabrication package** — source CAD and revision, printable exports, material, printer/process settings, orientation, supports, tolerances, inserts, and assembly instructions. Measure received hardware and correct dependent CAD before releasing custom parts.
4. **Test plan and evidence** — focused stress-test research, expected loads, measurable pass/fail criteria set before scored tests, test setup, results, photos/logs, and failures. Mark unrun tests **OPEN**, not passed.
5. **Exit decision** — `PASS`, `ITERATE`, or `HOLD`, with the evidence and the specific change needed. A failed or improved design becomes the next version; a passing subsystem can move forward while its shared interfaces remain tracked.

For the chassis, test at least fit and retention, loaded stiffness, wheel runout, traction and turning, braking and tipping, support/skid behaviour, motor temperature, and service access. Use representative worst-case body/head ballast until those assemblies exist. Reuse the [RP-03 locomotion gates](../02-prototypes/RP-03-locomotion/gates.md) and [RP-06 open items](../02-prototypes/RP-06-cad/TODO.md) as inputs; register relevant numeric limits and test conditions before scoring a run.

The working loop is **select → order → measure → update CAD → release → print/assemble → test → record → iterate or lock**. `LOCKED` means the built article passed its defined tests and its interfaces are controlled. A CAD check or paper calculation alone does not lock a part.

## Documentation rule

Keep these pages shorter and more decisive than [02-prototypes](../02-prototypes/). Link to existing research instead of copying it. State the current decision, revision, evidence, open risk, and next action; remove abandoned options from the active build instructions. Do not call estimates measurements or let a later CAD edit silently change a released version.

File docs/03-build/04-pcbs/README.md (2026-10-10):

# 04 — PCBs

This folder holds the schematic, layout, fabrication and electrical-validation work for the robot's custom boards. It is a work area, not a fabrication release. Part records stay in the [project BOM](../BOM.csv); every selection and change goes in the [build decisions](../decisions.md). It replaces the former `04-custom-pcb/` folder ([D-038](../decisions.md#d-038)).

## Board register

| ID | Board | Location | BOM | Status | Work still required |
|---|---|---|---|---|---|
| PCB-01 | 2S pack protection | Chassis tub, on the pack | CH-023 | **Bought:** Robocraze TIFPS0629 ([D-019](../decisions.md#d-019)); the RP-02 custom design is reference only | Bench acceptance before cells: [power-boards.md §3](power-boards.md#3-pcb-01--tifps0629-acceptance-before-cells-are-connected) |
| PCB-02 | Charger (BQ25798), on/off latch, pack sense, `ENERGY_OK` | Body, behind the rear panel (vertical) | CH-041 | Spec; charger block closed in [charge-path.md](charge-path.md) ([D-040](../decisions.md#d-040)); power-button input `J2-9` and the press → `SYSTEM_ARM` reset in [power-boards.md §6](power-boards.md#6-pcb-02-power-button-input-d-041) ([D-041](../decisions.md#d-041)) | Schematic; latch tests; power-button bench PB-01 to PB-06; charge bench CP-04 to CP-12; mounting (none in CAD yet) |
| PCB-03 | Motor gate, permit chain, head 5 V rail, drive feeds | Body, above the tub | CH-042 | Spec, with [build deltas](power-boards.md#2-pcb-03-drive-feed-for-the-drv8833); no E-stop loop: `J3-7` deleted, 0 Ω link in the permit chain (D-041) | Schematic; truth table, fault, inrush, regeneration tests |
| PCB-04 | Five branch converters (C2, base, Pi, display, audio) | Body, under the compute tray | CH-043 | Spec | Schematic; start-up, hold-up, breaker and back-feed tests |
| PCB-05 | Audio front end (MAX98357A, 2 × ADAU7002) | Body, above the Pi | BO-002 | Spec | Schematic and layout |
| PCB-06 ×4 | PDM microphone board | Body shell bosses | BO-005 | Spec | Layout; array tap and noise tests |
| PCB-07 | Base IMU (ICM-42688-P) | Chassis | CH-021 | HOLD | Sensor and SPI vs I²C interface |
| PCB-08 | Yaw junction (clock-spring stationary end) | Body, under the yaw adapter plate | CH-083 | Spec; grows +X to X 20 for two 22-pin 0.5 mm ZIFs, `J8-6` power and `J8-7` sideband, taking the cassette FFCs ([D-044](../decisions.md#d-044)) | Schematic; FFC pin order (power on 7 + 7 conductors for the pitch/roll pair, 2 + 2 each for C2 and display). Body-side pinout and the mating rule: [05-harness](../05-harness/README.md) (D-039) |
| PCB-14 | Yaw rotor joiner boards ([D-052](../decisions.md#d-052); replaces the D-044 Ø35 ring): three identical vertical 0.8 mm boards, each a straight 1:1 22-pin 0.5 mm FFC joiner with a down-facing side-entry ZIF for its cassette FFC (`W37`/`W42`/`W43`) and an up-facing one for the head FFC, both on the +Y face, 16.8 mm apart; tabs seat in the rotor posts | Body, inside the rotating yaw hub (Z 133.9–150.7) | BO-062 (×3) | HOLD | Select a ZIF ≤ 2.0 mm tall and ≤ 5.2 mm deep with its actuator; lay out the 1:1 joiner (power pins wide enough for the paralleled `W42` conductors); CSI signal check through two ZIF pairs |
| PCB-09 | C0 link adapter (2 × RS-422, audio pass-through, enclosure-fan switch `J9-4`) | Body, on the Pi header | CH-084 | Spec; fan switch added ([D-042](../decisions.md#d-042)): Pi GPIO24 → logic-level N-MOSFET low side, XH2.54-2P `J9-4` | Schematic; bench fit beside the yaw servo; GPIO24 needs a `CA-06` change request (CR-02) |
| PCB-10 | C3 controller carrier (watchdog, READY, sleep gate, Hall and TCRT circuits) | Body, −Y side wall | CH-044 | Spec | J10-8 Hall and J10-10 TCRT changes; [J10-5/6 driver mapping](power-boards.md#24-logic-to-c3-j10-5--j10-6-gh-6) |
| PCB-11 | Status LED carrier (WS2812B-2020) | Head crown | CH-085 | Spec | Brightness and stray-light bench |
| PCB-12 | C2 head carrier (ESP32-S3-Zero, transceivers, TPS3436 watchdog) | Head | CH-086 | Lead design | Schematic; head pocket fit |
| CH-064 | Nose Hall carrier (DRV5055) | Chassis nose | CH-064 | Spec | Layout of the 6 × 4.6 × 0.8 mm board |
| PCB-13 | Charge inlet: GCT USB4140, TVS2200, ESDA25W, STUSB4500, input P-FET | Body, rear-panel pad (comes off with the panel) | BO-015 | Spec and CAD ([charge-path.md §3, §6](charge-path.md), [D-040](../decisions.md#d-040)) | Schematic and layout; NVM image and read-back; CP-01 to CP-03, CP-13, CP-14 |

Power-board specification: the RP-02 [board-specs.md](../../02-prototypes/RP-02-electrical/board-specs.md) is the read-only reference, and [power-boards.md](power-boards.md) holds what the build changes. The charge path, from the USB-C inlet to the pack entry, is in [charge-path.md](charge-path.md). Open board work without another home is tracked in [open-items.md](open-items.md).

## Rules

The board outlines in CAD are packaging assumptions. They imply no Gerbers, completed schematic or passed board test.

Basic chassis fit and controlled motor tests can use a regulated bench supply, a development controller, driver boards and a temporary harness. Hall and bare-TCRT circuits can be prototyped separately. Full custom-board fabrication is not a prerequisite for those tests. Battery-powered and integrated sensor/control tests keep their protection, interface and validation requirements.

Before releasing any board, record:

- its exact revision, schematic, BOM and layout;
- connector pinout, protection and enable behaviour;
- mounting dimensions and fabrication/assembly outputs;
- measured electrical results.

When an interface changes, update the affected CAD and the canonical BOM.

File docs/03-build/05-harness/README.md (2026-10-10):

# 05 — Harness: connectors, wires and service breaks

| Field | Value |
|---|---|
| Status | Working design, 2026-10-04 ([D-039](../decisions.md#d-039)). Nothing bought, crimped or bench-tested |
| Governs | Every installed cable in the body and chassis, from the pack lead to the yaw junction (PCB-08). Head-internal wiring stays with RP-01 Layout 04 |
| Replaces | RP-06 [connector-schedule.md](../../02-prototypes/RP-06-cad/connector-schedule.md) §3 and §5 for the build. That schedule stays read-only reference; §8 lists the rows changed here |
| Inputs | [04-pcbs/power-boards.md](../04-pcbs/power-boards.md), RP-02 [board-specs.md](../../02-prototypes/RP-02-electrical/board-specs.md), the chassis and body CAD |
| Check | [`check_harness.py`](../01-chassis/v1/cad/check_harness.py) (about 30 s): connector reserves and bodies, edge fit, slide path, NTC break and splices. Result: `generated/harness-checks.json`, **ALL PASS** on 2026-10-04 |
| Evidence labels | `D` vendor data read, `E` estimate, `U` unknown, `W` measured. No `W` value exists yet |

## 1. Decisions

| ID | Decision | Why |
|---|---|---|
| H-01 | **The fused pack feed splits at the fuse** (builder, 2026-10-04). Fuse output and pack negative each fork at a crimped butt splice above the PCB-03 +Y edge. One branch goes to PCB-03 `J3-1` (motors, head), the other to PCB-02 `J2-1` (charger, `OPBUS`). **`W04` and `J2-2` are deleted.** The negative splice is the power star (`PA-15`) | The old path (pack → fuse → PCB-02 on the rear panel → back to PCB-03) had four mated connectors and about 0.5 m of wire. The split halves the pack-to-gate resistance (§6) |
| H-02 | **`J-PK` is the isolator.** Unplug it before mating or unmating `J2-1` or `J3-1`. Every other connector mates and unmates only in `OFF` with the charger unplugged | In `OFF` every body rail is dead (`OPBUS` open, gate open), so a half-mated plug cannot back-power a domain. Only `BATBUS` is live, and it reaches `J2-1`/`J3-1` alone. Micro-Fit parts have no first-mate pins, so the rule is procedural, not mechanical |
| H-03 | **Power and signal never share a housing.** Power is on Micro-Fit+ and Micro-Fit 3.0; signals are on JST GH. The only supplies inside a GH housing are a sensor's own low-current feed (encoder, IMU, nose, TCRT) | `power-implementation-basis.md` §4 and CN-02 |
| H-04 | **Two crimp families, one tool each.** Micro-Fit+ carries only AWG16/18 (Molex 213309-4400). Micro-Fit 3.0 carries only AWG20–24 (one 20–24 AWG tool). **No GH crimping:** every GH cable is a pre-crimped JST GH lead, single-ended where the far end is soldered | A Micro-Fit+ tool covers one gauge pair. AWG20/24 on Micro-Fit+ would need two more tools. GH crimping by hand is unreliable |
| H-05 | **Micro-Fit+ leads use thin-wall wire, UL1061 class (insulation OD ≤ 2.0 mm), not silicone.** This includes the pack lead `W01` | The 206460 16 AWG terminal is specified for 2.00 mm insulation (`D`), and the Molex hand tool for UL1061 wire (`D`). Fine-strand silicone AWG16 is about 2.3–2.6 mm, so the insulation grip would not close |
| H-06 | **`J3-4` and `J8-1` move from Micro-Fit+ to Micro-Fit 3.0.** `J8-1` becomes a 2×3 (43045-0600 class) carrying the pitch/roll pair from `J3-4` and the C2 and display pairs from `J4-2`, all AWG22 | The head trunk's design current is 1.0 A (3.6 A worst stall). Micro-Fit 3.0 at AWG22 carries it, and every head-side power conductor stays on one tool. `J3-4` frees 1.0 mm of PCB-03 −Y edge (margin 0.4 → 1.44 mm) |
| H-07 | **Pack NTC break: a JST SM 2-way wire-to-wire pair**, pre-wired pigtails soldered on, lying in the +Y channel ahead of `J-PK` (X 52–76, Z 41.6–47.4) | GH has no wire-to-wire housing, and the channel holds nothing wider than about 8 mm. The space was freed when the fuse moved up (D-032). The pair's 6.5 × 5.8 mm section passes the 22.6 × 10 mm tub window |
| H-08 | **The body lifts off after 11 plugs (12 with the IMU) are pulled at the body-side boards** (§7.2). There is no separate chassis-body bulkhead connector | The shell must come off to reach the J13 bolts anyway, and that opens access to PCB-02/03 and the C3 carrier. A bulkhead would put two more mated contacts in every chassis lead, including the motor feeds |
| H-09 | **Encoders run from the C3 carrier 3V3, not 5 V** | The MOT3001 Hall board accepts 3.3–5 V (`E`, family data). On 5 V its pulled-up outputs would exceed the ESP32-S3's 3.6 V input limit |

## 2. Power tree as wired

```
 CHASSIS                                                   BODY (frame-mounted)
 cells ─ PCB-01 ─W01─ J-PK ─W03a─ FUSE 15 A ─W03b─ (+)splice ─W03c─ J3-1  PCB-03 ─J3-2/3─W06/07─ #3297 L/R (chassis)
                        │                                 └──────W03d─ J2-1  PCB-02 ─J2-3─W05─ J4-3 PCB-04
                        └────────────W03a−──────────── (−)STAR splice ─W03c/d (−)
 NTC ─W02a─ SM 2p break ─W02b───────────────────────────────────── J2-7  PCB-02 (BQ25798 TS)
 USB-C adapter ─ PCB-13 (rear panel; STUSB4500, input switch) ─W16─────── J2-8  PCB-02 (BQ25798 VBUS)
```

## 3. Connector families and parts

| Family | Use | Housing | Terminal | Wire | Tool |
|---|---|---|---|---|---|
| Micro-Fit+ 3.0 mm | `J-PK` (wire-to-wire), `J3-1`, `J2-1`, `J3-2`, `J3-3`, `J4-1` (1×2); `J2-3`, `J4-3` (2×2) | Single-row receptacle (215759 series, `D` family) or dual row (206461-0200 for 2×2-class); exact PN at order (`U`) | Female 206460-0041, tin, 16 AWG, 13 A (`D`); 18 AWG sibling; male 215953 series for the `J-PK` plug half (`U`) | AWG16/18 UL1061 | Molex 213309-4400, 16/18 AWG UL1061 (`D`) |
| Micro-Fit 3.0 | `J3-4`, `J4-2`, `J4-4`, `J4-5`, `J5-7`, `J8-1`, `J10-1`, `J2-8` (D-040), motor inline pairs | 43025 receptacle; 43645/43640 wire-to-wire (`D`) | Female 43030-0007, 20–24 AWG, 8.5 A max (`D`); male 43031 series | AWG22 (motor pairs: the MOT3001's own leads) | Molex 63819-0900 20–24 AWG (`E`, confirm the tool PN) |
| JST GH 1.25 mm | All signals | GHR-xxV-S | Pre-crimped leads (SSHL-002T-P0.2 on AWG28) | AWG28 pre-crimped, double- or single-ended | None. Engineer PA-09 class only for re-pinning |
| JST SM 2.5 mm | Pack NTC break | SMP-02V-BC / SMR-02V-B | Pre-wired pigtail pair | AWG22–26 pigtails, soldered | None |
| 5264-3P servo | Feetech ST3215-HS yaw `J3-5`; STS3045M pitch/roll within head | Feetech/Waveshare 3-pin cable; [Waveshare states ST-series compatibility](https://www.waveshare.com/sr-cable-5264-3pin.htm) | Vendor | Vendor lead, current rating to confirm | None |
| Butt splice | `BATBUS` + and − forks | Insulated 12–10 AWG seamless butt splice: 2 × AWG16 in one end, 1 × AWG16 folded double in the other; adhesive dual-wall heat-shrink over it | — | AWG16 | Ratcheting insulated-terminal crimper |
| USB-C plug | Pi 5 power `W10` | Right-angle, solder type, cable exiting down (−Z), body ≤ 13 mm beyond the Pi edge (D-048), with a 56 kΩ Rp from CC to VBUS inside the shell (CN-03) | Soldered | AWG18 | Soldering iron |

## 4. Wire list

Lengths are `E`: Manhattan routes through CAD waypoints plus service slack. Cut at the first harness build and record as `W`. "P" means pre-crimped GH; "S" means soldered.

### 4.1 Pack and power

| Cable | From → to | Ends | Conductors | Length | Route |
|---|---|---|---|---|---|
| `W01` pack lead | Pack P+ (cell stack) / TIFPS0629 P− → `J-PK` pack half | S / Micro-Fit+ 1×2 male | 2 × AWG16 UL1061 red/black | 120 | Out through the +Y tub window into the channel |
| `W02a` NTC, pack side | 103AT-2 on the cell → SM 2p plug | S / SM pigtail (S) | 2 × AWG26 | 100 | With `W01`, through the window, forward in the channel |
| `W02b` NTC, body side | SM 2p receptacle → PCB-02 `J2-7` | S / GH 2 (P, single-ended) | 2 × AWG28 | 240 | Up past the fuse, along the +Y side to the PCB-02 top layer |
| `W03a` fused feed + | `J-PK` body half → fuse holder input (front end, X 82) | Micro-Fit+ 1×2 female / crimp onto holder lead | 1 × AWG16 | 110 | Channel, up the front of the fuse bracket |
| `W03a−` pack − | `J-PK` body half → negative star splice | Micro-Fit+ / splice | 1 × AWG16 | 70 | Up beside the bracket |
| `W03b` | Fuse holder output (rear end, X 52) → + splice | Holder lead / splice | 1 × AWG16 | 30 | Straight back |
| `W03c` BATBUS-M | Splices → PCB-03 `J3-1` | Splice / Micro-Fit+ 1×2 | 2 × AWG16 | 60 | Splices to `J3-1` (2.65 mm gap in CAD) |
| `W03d` BATBUS-C | Splices → PCB-02 `J2-1` | Splice / Micro-Fit+ 1×2 | 2 × AWG16 | 220 | Rearward along +Y, across behind PCB-04 to the PCB-02 −Y edge |
| ~~`W04`~~ | Deleted (H-01) | | | | |
| `W05` `OPBUS` + `CHGBUS` | PCB-02 `J2-3` → PCB-04 `J4-3` | Micro-Fit+ 2×2 both ends | 4 × AWG18 | 170 | Under-board slot to the PCB-04 +Y edge |
| `W06`/`W07` `PB-DRIVE-L/R` | PCB-03 `J3-2`/`J3-3` → #3297 `VM`/`GND` pins (power-boards §2.3) | Micro-Fit+ 1×2 / S, with 100 µF + 0.1 µF at `VM` | 2 × AWG18 each | 50 | Edge to the adjacent driver |
| `W08`/`W09` motor L/R | #3297 `AOUT1+BOUT1` / `AOUT2+BOUT2` (bridges paralleled) → MOT3001 motor pair | S at the board / Micro-Fit 3.0 1×2 wire-to-wire at the inline reserve | Driver side 2 × AWG22; motor side the MOT3001's own leads | 230 | Motor connector → across the deck behind the posts (`HARNESS_MOTOR_BRANCH`) → tie bridge (CH-082) → inline pair |
| `W10` `PB-COMPUTE` | PCB-04 `J4-1` → Pi 5 USB-C | Micro-Fit+ 1×2 / right-angle USB-C plug (S) | 2 × AWG18 | 100 | Pi −Y edge, down past the tray (`PI5_POWER_PIGTAIL_DROP`) |
| `W11` `PB-SAFE-BASE` | PCB-04 `J4-4` → C3 `J10-1` | Micro-Fit 3.0 2×1 both ends | 2 × AWG22 | 110 | −Y side up to the carrier front edge |
| `W12` `PB-AUDIO-OUT` | PCB-04 `J4-5` → PCB-05 `J5-7` | Micro-Fit 3.0 2×1 both ends | 2 × AWG22 | 160 | +Y, then forward (BO-006) |
| `W13` `PB-HEAD-PR` pitch/roll | PCB-03 `J3-4` → PCB-08 `J8-1` pins 1/4 | Micro-Fit 3.0 2×1 / one leg of the `J8-1` 2×3 plug | 2 × AWG22 | 160 | 5.5 V setpoint; 2.8 A aligned head-servo stall allowance at the 6 V datasheet point, pending B1; −Y riser (`HARNESS_HEAD_RISER_*`) |
| `W14` `PB-SAFE-C2` + `PB-DISPLAY` | PCB-04 `J4-2` → `J8-1` pins 2/5 and 3/6 | Micro-Fit 3.0 2×2 / the other leg of the `J8-1` plug | 4 × AWG22 | 140 | −Y riser, joins `W13` in one sleeve |
| `W15` yaw servo | PCB-03 `J3-5` → ST3215-HS | Waveshare/Feetech 5264-3P servo lead | Vendor, current rating to confirm | 120 target; stocked leads are longer and need restraint | **12 V yaw-only supply**, GND and shared `SERVO_DATA`; routing and connector position to recheck after yaw-bay fit |
| `W16` charge inlet ([D-040](../decisions.md#d-040)) | PCB-13 on the rear panel → PCB-02 `J2-8` | S / Micro-Fit 3.0 2-way (43025, female on the cable) | 2 × AWG22 (`VSNK`, `GND`) | 150 | +Y through the gap behind PCB-02 (`CHARGE_INLET_W16_LEAD_RESERVE_1/2`), forward to the `J2-8` plug on the PCB-02 +Y edge. Unplug before lifting the rear panel away |

### 4.2 Signals (all GH, AWG28 pre-crimped)

| Cable | From → to | Leads | Length | Notes |
|---|---|---|---|---|
| `W20` | PCB-02 `J2-4` ↔ PCB-04 `J4-6` | GH10, double-ended | 60 | |
| `W21` | `J2-5` ↔ PCB-03 `J3-6` | GH6, double-ended | 110 | |
| ~~`W22` E-stop~~ | Deleted ([D-041](../decisions.md#d-041)): there is no E-stop and no `J3-7` | — | — | |
| `W23a` | PCB-08 `J8-3` ↔ `J3-8` | GH8, double-ended | 200 | −Y riser |
| `W23b` | `J8-5` ↔ `J2-6` | GH8, double-ended | 160 | −Y riser |
| `W24` head link | PCB-09 `J9-1` ↔ `J8-4` | GH6, double-ended, pairs twisted | 170 | RS-422 |
| `W25` base link | `J9-2` ↔ C3 `J10-2` | GH6, double-ended, pairs twisted | 200 | RS-422 |
| `W26`–`W28` audio | Per [02-body BOM](../02-body/v1/BOM.md) (BO-006) | — | — | Unchanged |
| `W29` IMU | PCB-07 ↔ `J10-7` | GH8 | — | PCB-07 is HOLD; its lead is in the IMU mass row |
| `W30`/`W31` encoders | MOT3001 encoder wires (cut from the vendor cable, ~60 mm kept) → `J10-3`/`J10-4` | GH4, single-ended, soldered to the vendor wires under heat-shrink | 220/230 | Along the deck, up the −Y side |
| `W32`/`W33` driver logic | #3297 `SLP`, `AIN1+BIN1`, `AIN2+BIN2`, `FLT`, `GND` → `J10-5`/`J10-6` | GH6, single-ended (S at the board) | 180/80 | D-038 mapping |
| `W34` nose | GP2Y0A21 (S) and the Hall board pads (S) → `J10-8` | GH5, single-ended | 220 | `HARNESS_NOSE_J10_8_*` route (D-013, D-027) |
| `W36` rear TCRT | TCRT5000 legs (S) → `J10-10` | GH4, 350 mm single-ended (CH-020) | 350 | [rear-tcrt-lead.md](../01-chassis/v1/research/rear-tcrt-lead.md) |
| `W37` CSI | Pi 5 ↔ PCB-14 (head side: PCB-14 ↔ Camera Module 3) | 22-pin 0.5 mm FFC, about 200 mm (Raspberry Pi 5 camera cable), through the yaw cassette | — | Changed by [D-044](../decisions.md#d-044): it now crosses yaw in the FFC cassette (BO-050) and demates at PCB-14. [D-052](../decisions.md#d-052): enters the drum through the 0° slit, one 45° fold, into its joiner board's lower ZIF; the head-side cable must stay 22-pin width (11.5 mm) through the Ø21 disc bore and channel, so any 15-pin transition to the Camera Module 3 is inside the head |
| `W42` yaw power FFC | PCB-08 `J8-6` ↔ PCB-14 (head side: a 22-pin 0.5 mm FFC from PCB-14 through the disc channel, D-052) | 22-pin 0.5 mm FFC, about 200 mm, in the cassette | — | Carries the three `J8-1` power pairs (7 + 7 head-servo, 2 + 2 C2, 2 + 2 display conductors). The 2.8 A aligned head stall divides to 0.40 A per parallel head conductor **only with verified equal sharing**; check FFC/contact ampacity and heat. The 12 V yaw supply stays on the body side |
| `W43` yaw sideband FFC | PCB-08 `J8-7` ↔ PCB-14 (head side: a 22-pin 0.5 mm FFC from PCB-14 through the disc channel, D-052) | 22-pin 0.5 mm FFC, about 200 mm, in the cassette | — | D-044: the `J8-3`, `J8-5` and `J8-4` signals, spares dropped |
| ~~`W38`~~ | Not fitted (D-041): `J10-11` carried the E-stop status | — | — | |
| `W39` | `J10-12` ↔ `J3-9` | GH4, double-ended | 100 | |
| `W40` power button ([D-041](../decisions.md#d-041)) | Mushroom NO terminals (S, heat-shrink) → PCB-02 `J2-9` | GH2, single-ended | 150 | Out past the contact block, +Y beside the Pi's rear edge, back above the PCB-02 +Y edge and down to `J2-9` (`POWER_BUTTON_W40_LEAD_RESERVE_1…4`). Rides with the rear panel; unplug at `J2-9` before lifting the panel away |
| `W41` enclosure fan ([D-042](../decisions.md#d-042)) | BO-040 fan leads → PCB-09 `J9-4` | XH2.54-2P, the fan's own 2-wire lead (30 cm as bought), cut to ~80 mm and re-crimped into its housing | ~80 | Along `HARNESS_W41_FAN_LEAD_1/2`: from the fan's top-front corner along −Y above PCB-09's top-entry plugs to `J9-4`. `J9-4` pin 1 is FAN+ (5 V from the 40-pin header), pin 2 is FAN− (drain of the PCB-09 low-side MOSFET, switched by Pi GPIO24). Unplug at `J9-4` to remove the fan or PCB-09 |

**Pre-crimped GH lead buy list** (lengths rounded up to the stock 50/100/150/200/300 mm, one spare of each):

| Circuits | Double-ended | Single-ended |
|---|---|---|
| GH2 | — | 1 × 300 (`W02b`), 1 × 150 (`W40`) |
| GH3 | — (`W38` not fitted, D-041) | — |
| GH4 | 1 × 150 (`W39`) | 2 × 300 (`W30`/`W31`); `W36` 350 already on CH-020 (`W22` deleted, D-041) |
| GH5 | — | 1 × 300 (`W34`) |
| GH6 | 1 × 150 (`W21`), 1 × 200 (`W24`), 1 × 300 (`W25`) | 1 × 200 (`W32`), 1 × 100 (`W33`) |
| GH8 | 1 × 300 (`W23a`), 1 × 200 (`W23b`) | — |
| GH10 | 1 × 100 (`W20`) | — |

**Wire stock.** AWG16 UL1061 3 m red + 3 m black (needs about 1.0 m). AWG18 UL1061 3 m + 3 m (about 1.1 m). AWG22 stranded 5 m + 5 m (about 1.4 m). AWG26 1 m pair for the NTC. 3:1 adhesive heat-shrink in 3.2/4.8/6.4 mm sizes, and 4 mm braided sleeving for the −Y riser bundle.

## 5. Pinouts

Pin 1 is the housing's marked cavity. On a dual-row Micro-Fit, pins 1…n are the latch row and the second row continues under them. **Rule:** on 2-circuit power, pin 1 is +, pin 2 is the return. On dual-row power, each return sits directly opposite its supply.

### 5.1 Power

| Connector | Pins |
|---|---|
| `J-PK` (Micro-Fit+ 1×2) | 1 PACK+, 2 PACK− |
| `J3-1`, `J2-1` (Micro-Fit+ 1×2) | 1 BATBUS+, 2 PGND (star) |
| `J2-3` ↔ `J4-3` (Micro-Fit+ 2×2) | 1 OPBUS, 2 CHGBUS, 3 OPBUS_RTN, 4 CHGBUS_RTN |
| `J3-2`, `J3-3` (Micro-Fit+ 1×2) | 1 PB-DRIVE+, 2 GND |
| `J4-1` (Micro-Fit+ 1×2) | 1 +5V15_PI, 2 GND |
| `J4-4` ↔ `J10-1`, `J4-5` ↔ `J5-7` (Micro-Fit 3.0 2×1) | 1 +5 V branch, 2 GND |
| `J3-4` (Micro-Fit 3.0 2×1) | 1 +5V5_HEAD_PR, 2 GND_HEAD |
| `J4-2` (Micro-Fit 3.0 2×2) | 1 +5V_C2, 2 +5V_DISPLAY, 3 GND_C2, 4 GND_DISPLAY |
| `J8-1` (Micro-Fit 3.0 2×3) | 1 +5V5_HEAD_PR, 2 +5V_C2, 3 +5V_DISPLAY, 4 GND_HEAD, 5 GND_C2, 6 GND_DISPLAY |
| Motor inline (Micro-Fit 3.0 1×2 wire-to-wire) | 1 OUT1 (`AOUT1+BOUT1`), 2 OUT2 (`AOUT2+BOUT2`). Set the forward sense in firmware after the first spin |
| NTC break (SM 2p) | 1 TS, 2 TS_RTN (thermistor; polarity-free) |
| `J2-7` (GH2) | 1 TS, 2 TS_RTN. TS_RTN is the BQ25798 ground pad on PCB-02, never a cell or B− (charge-path.md §4) |
| `J2-8` (Micro-Fit 3.0 2×1) | 1 VSNK, 2 GND. Female contacts on the `W16` cable side, which is the source (D-040) |

### 5.2 Signals

Each GH cable puts GND at pin 1 where it carries no supply, and keeps each differential or analog signal next to its return.

| Connector | 1 | 2 | 3 | 4 | 5 | 6 | 7 | 8 | 9 | 10 |
|---|---|---|---|---|---|---|---|---|---|---|
| `J2-4` ↔ `J4-6` (`W20`) | GND | +5V_C2 (pull-up supply to PCB-02) | PG_C2 | PG_BASE | SEQ_EN (latch out) | PG_COMPUTE | PG_DISPLAY | PG_AUDIO | spare | GND |
| `J2-5` ↔ `J3-6` (`W21`) | GND | CHARGE_ABSENT | ENERGY_OK | SYSTEM_ARM | MOTOR_PRESENT | GND | | | | |
| `J3-8` ↔ `J8-3` (`W23a`) | SIG_REF | SERVO_DATA | C2_READY_H | C2_READY_L | spare (was E_STOP_STATUS, D-041) | MOTOR_PRESENT | HEAD_OC | HEAD_PGOOD | | |
| `J2-6` ↔ `J8-5` (`W23b`) | SIG_GND | V_PACK_ANA | SIG_GND | STAT | INT_PB | KILL | CHG_ABSENT_3V3 | spare | | |
| `J9-1` ↔ `J8-4`, `J9-2` ↔ `J10-2` | GND | TX+ | TX− | RX+ | RX− | spare | | | | |
| `J10-3`/`J10-4` (`W30`/`W31`) | GND | +3V3_ENC | ENC_A | ENC_B | | | | | | |
| `J10-5`/`J10-6` (`W32`/`W33`) | SLP | IN1 | IN2 | FLT | GND | spare | | | | |
| `J10-7` (`W29`) | +3V3 | GND | SCLK | MOSI | MISO | CS | INT1 | INT2 | | |
| `J10-8` (`W34`) | +5V (GP2Y) | GND | GP2Y_VO | +3V3 (Hall) | HALL_OUT | | | | | |
| `J10-10` (`W36`) | LED_A | LED_K | TCRT_OUT | GND | | | | | | |
| `J10-12` ↔ `J3-9` (`W39`) | GND | C3_READY | MOTOR_PRESENT | GND | | | | | | |
| `J2-9` (`W40`) | PB_SW (10 kΩ to latch `VIN`, 5.1 kΩ to `PB`) | GND | | | | | | | | |
| `J9-4` (`W41`, XH2.54) | FAN+ (+5 V, 40-pin header) | FAN− (low-side MOSFET drain; Pi GPIO24 `FAN_EN`) | | | | | | | | |
| `J3-5` (Feetech 5264-3P mating header; verify footprint) | GND | +12V_YAW | SERVO_DATA | | | | | | | |

**Servo bus electrical check (D-046/D-047).** The STS3045M [specification](https://pages.switch-science.com/comparison/files/feetech/serial-sts/STS3045M_datasheet.pdf) defines a 5264-3P lead as GND / Vcc / signal and recognizes a 2–5 V data high. Its supply is independent of that TTL signal. The ST3215-HS is in Waveshare's [ST-series 5264-3PIN cable family](https://www.waveshare.com/sr-cable-5264-3pin.htm). C2, two 5.5 V STS3045Ms and the 12 V ST3215-HS can therefore share **one signal net in principle**, provided all their grounds share a signal reference and the PCB-12 transceiver and every servo drive only a 3.3–5 V logic level. This is an electrical *hypothesis*, not a mixed-supply bus pass: measure idle/high/low voltage, rise time, turnaround contention, return current and error rate on the assembled W43/PCB-08/PCB-12/W15 path, including yaw at 12 V and head at 5.23 V. No 12 V pull-up may reach `SERVO_DATA` or C2. Confirm the received ST3215-HS cable cavity orientation before applying 12 V; the three logical functions in the table are not a license to copy the ROBOTIS EH footprint.

`J2-4`/`J4-6` signal names follow RP-02 §6.4. The schematic may rename them, but not move a supply onto an end pin. The `W20` +5V_C2 replaces the RP-02 §8 `+5V_C2` line, which had no cable. `J10-8` and `J10-10` are unchanged from [nose-hall-board.md](../01-chassis/v1/research/nose-hall-board.md) and [rear-tcrt-lead.md](../01-chassis/v1/research/rear-tcrt-lead.md); the nose sensor is now the GP2Y0A21YK0F (D-019), not the A41.

**Required at the receiving board (schematic):** a series resistor of 1 kΩ or more on every slow input that crosses a connector (READY, status and ADC lines), and 33–100 Ω on encoder and SPI lines. That keeps any half-mated or unpowered case to a few mA into ESD diodes (`PA-11.6`).

## 6. Calculations (`E`)

Resistance: AWG16 13.2, AWG18 21.0, AWG22 53, AWG28 213 mΩ/m at 20 °C, ×1.16 hot. Micro-Fit+ contact: 10 mΩ maximum (`D`), 2.5 mΩ typical assumed.

| Path | Wire | Contacts | Fuse, holder, splices | Total | Drop |
|---|---|---|---|---|---|
| Pack → PCB-03, split (H-01), typical | 8.7 mΩ | 4 × 2.5 = 10 mΩ | 6.4 mΩ | **25 mΩ** | 0.25 V at 10 A |
| Same, Molex maximum | 8.7 | 4 × 10 = 40 | 6.4 | **55 mΩ** | 0.55 V at 10 A |
| Old route via PCB-02, typical / maximum | — | 8 contacts | — | 44 / 104 mΩ | 0.44 / 1.04 V |
| `W10` Pi feed (AWG18, 100 mm, Micro-Fit+, USB-C) | | | | 18 mΩ | 43 mV at 2.4 A, 90 mV at 5 A; inside the 100 mV steady allowance |
| `W13` body side (AWG22, 2 Micro-Fit 3.0 mates) | | | | 40 mΩ | 40 mV at 1.0 A design, 143 mV at a 3.6 A stall; the 150 mV budget's body share holds at design |

- **Against the ledger.** The 10 mΩ wiring allowance in the pack model (`2·22 + 30 + 10`) was low. With the split, the pack model becomes 44 + ≤ 30 (TIFPS0629 acceptance) + 25 ≈ **99 mΩ** typical. That is still inside the ledger's 80–100 mΩ range, but at its top. RP-02 §8.1 corner D (cold, aged) should be recomputed with the measured path. Measure it (4-wire, 5 A) in Phase C.
- **Currents against ratings.** `BATBUS` peak is about 10.2 A (power-boards §4). `J-PK` and `J3-1` carry all of it, against 13 A per Micro-Fit+ AWG16 contact (`D`). `J2-1` carries `OPBUS` plus charge, about 5.5 A worst. Fuse: 15 A ATOF (CH-029). The drive feeds take 2.4 A, the head trunk 1.0 A (3.6 A worst), and Micro-Fit 3.0 is rated 8.5 A (`D`).
- **Mass.** Conductors about 45 g, plugs, splices, sleeving and ties about 28 g: **about 73 g**. This excludes the pack lead, IMU lead, TCRT lead and audio cables, which have their own mass rows. The `HARNESS_AND_FASTENERS` row is 95 g, which leaves about 22 g for loose fasteners. The register is unchanged; weigh the built harness.

## 7. Service procedures

### 7.1 Pack out

1. Put the robot in `OFF` and unplug the charger.
2. Remove the four J11A screws and lower the hatch with the pack strapped to it.
3. Slide the `J-PK` pair in through the tub window and unplug it.
4. Pull the NTC pair back to the window and unplug it.
5. The pack is free. Refit in reverse: NTC first, then `J-PK`.

### 7.2 Body off the chassis

1. Pack out (7.1), or at least `J-PK` open (H-02).
2. Remove the shell (body README) and the rear service panel. Draw the panel out along −X and unplug `W16` at `J2-8` and `W40` at `J2-9` (both on PCB-02's +Y edge) before setting it aside; PCB-13 and the power button stay on the panel (D-040, D-041).
3. Unplug the 11 chassis leads at the body boards:
   - `J3-1` and `J2-1`: the `BATBUS` branches. Their splices stay with the chassis.
   - `J3-2` and `J3-3`: the drive feeds.
   - `J2-7`: the NTC.
   - `J10-3`, `J10-4`, `J10-5`, `J10-6`, `J10-8`: encoders, driver logic and nose.
   - `J10-10`: rear TCRT.
4. Leave `J10-7` (IMU) to come off with its lead, or unplug it too if PCB-07 is fitted. That makes 12.
5. Undo J13 and lift the body (body README §Body frame/chassis assembly).

Every chassis-side lead carries at least 40 mm of slack at its body-side plug, so the plug can be withdrawn before the body moves. **Check hand and tool reach at the first assembly.** PCB-03's edge plugs sit under the compute tray at Z 64–75 and are reached from ±Y with the shell off.

### 7.3 Head off

Unchanged (connector-schedule §3.4): unplug `J8-1`, `J8-3`, `J8-4`, `J8-5` and the CSI at the Pi, then lift the head with PCB-08.

## 8. Changes to the RP-06 schedule rows

| Row | Was | Now |
|---|---|---|
| `W01` | AWG16 silicone | AWG16 UL1061 (H-05) |
| `W02` | GH2 straight to `J2-7`, break open | `W02a`/`W02b` with the SM 2p break in the channel (H-07) |
| `W03`/`W04` | Fuse on a PCB holder → PCB-02 → `W04` → PCB-03 | Inline holder (D-032), split at splices; `W04` and `J2-2` deleted (H-01) |
| `W06`/`W07` | DRV8874 carrier `VIN` | #3297 `VM` pin (D-038) |
| `W08`/`W09` | #4804 leads | MOT3001 cut lead, Micro-Fit 3.0 inline pair, paralleled outputs |
| `W13`/`W14`, `J8-1` | Micro-Fit+ 1×2 + Micro-Fit 3.0 2×2 into a Micro-Fit+ 2×3 | All Micro-Fit 3.0 AWG22, one 2×3 plug (H-06) |
| `W30`/`W31` | #4804 encoder, Vcc 3.5–20 V | MOT3001 encoder on 3V3 (H-09) |
| `W32`/`W33` | DRV8874 `SLEEP`, `EN/IN1`, `PH/IN2`, `CS`, `FAULT` | DRV8833 `SLP`, `IN1`, `IN2`, `FLT` (D-038) |
| `W34` | GP2Y0A41 + tact switch, PH3 at the sensor | GP2Y0A21 + DRV5055 Hall, soldered at the sensor (D-013, D-019, D-027) |
| `W36` | 5 V/GND/analog/digital breakout | Bare TCRT lead, LED and load on PCB-10 (D-016) |
| §5 items 1, 6, 7, 8 | Open | Closed here: NTC break, pinouts and mating rule, tooling, wire list |

## 9. Open

- [ ] Molex housing and male-terminal part numbers for each Micro-Fit+ position (single-row 215759 receptacle and its plug). Confirm the 63819-0900 tool for 43030/43031. Get quotes; the Molex tools are the main cost.
- [ ] MOT3001 6-wire colour code and encoder supply range on receipt (`U`): meter the cable before cutting it.
- [ ] Received JST SM pair: measure its mated section against the 6.5 × 5.8 mm envelope.
- [ ] Crimp qualification: pull-test three samples per tool and gauge to IPC/WHMA-A-620 Class 2, and section one Micro-Fit+ AWG16 crimp.
- [ ] First harness build: cut-to-length values (`W`), the 4-wire pack → `J3-1` resistance at 5 A, and hand reach for the 12 body-lift plugs. Then weigh the harness against §6.
- [ ] The body model (`02-body/v1/cad/body_v1_model.py`) carries pre-D-031 driver positions and the pre-D-032 fuse envelope. Its PCB-03 edge reserves clash with the stale drivers, and its PCB-04 edge reserves and the `J4-1` plug clash with `BODY_FRAME_MAIN_PRINT` (108 mm³ per reserve, 45.7 mm³ at `J4-1`). These clashes predate D-039 and were confirmed against the HEAD model. The frame/PCB-04 edge clash is real body-v1 geometry and must be fixed before the frame is printed.
- [ ] `body_v1_model.wheel_assembly()` raises `NameError: WHEEL_MODEL` (pre-existing).

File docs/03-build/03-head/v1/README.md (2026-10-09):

# Head v1

The head v1 CAD is in [cad/](cad/README.md). It is based on the latest RP-06
Layout 04, with its source and purchased geometry moved into the build tree.
The head now shares body v1's yaw datum and has modeled M3 disc fixings to
its three hub inserts. [The integrated export](cad/head-v1-integrated.step.py)
builds the head on the latest body v1 and chassis v1 source; the standalone
[head export](cad/head-v1.step.py) supports head-only review.

The integrated CAD is a geometry and packaging handoff. The purchased fits,
print process and tolerances, cable flex, and measured balance remain physical
build checks before fabrication release.

The head's purchased parts and their selection state are in the
[head BOM](BOM.md).

The Feetech change is tracked in the [actuator screen](feetech-actuator-screen.md),
[revised storyboard](feetech-motion-storyboard.md), and
[bench protocol](feetech-bench-protocol.md). The head CAD in [cad/](cad/README.md)
installs both STS3045M servos ([D-049](../../decisions.md#d-049)); the head
exports were regenerated with them on 2026-10-08.

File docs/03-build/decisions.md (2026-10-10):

# 03 — Build decision ledger

The central record of every decision and change made during the build phase. Newest entries go at the bottom. Each entry states what was decided, why, what changed (docs, BOM, CAD), what is still unverified, and the next action. Supersede an entry with a new one instead of rewriting it.

`02-prototypes/` is read-only reference ([D-001](#d-001)); earlier RP decisions are linked, not copied or edited.

| ID | Date | Area | Decision | Status |
|---|---|---|---|---|
| [D-001](#d-001) | 2026-09-28 | Governance | `03-build/` governs; `02-prototypes/` is read-only reference | ACTIVE |
| [D-002](#d-002) | 2026-09-28 | Chassis / drive | DFRobot FIT0521 as drive gearmotor | SUPERSEDED by D-003 |
| [D-003](#d-003) | 2026-09-28 | Chassis / drive | Drive gearmotor: ThinkRobotics MOT3001-6V230RPM, with a reduced drive envelope | ACTIVE; inventory/workflow corrected by D-005 |
| [D-004](#d-004) | 2026-09-29 | Chassis / wheels | Wheel rim and tyre: six-spoke PETG rim with a clamped TPU tyre (A) or three O-rings (B) | SUPERSEDED by D-005 |
| [D-005](#d-005) | 2026-09-29 | Chassis / wheels | Wheel: TPU chevron tyre on a restyled clamped rim; O-rings as fallback only; spin index removed | ACTIVE for tyre, retention and fallback; face styling superseded by D-006 |
| [D-006](#d-006) | 2026-09-29 | Chassis / wheels | Wheel face: five swept blade spokes after builder references; round 5-screw clamp ring | SUPERSEDED by D-008 |
| [D-005](#d-005) | 2026-09-29 | Chassis / motor interface | No motor on hand; proceed with documented assumptions and replaceable interface | ACTIVE |
| [D-007](#d-007) | 2026-09-29 | Chassis / axle | Axle stack architecture: turned steel stub, paired bearings, set-screw motor coupling, floating motor | ACTIVE for architecture; bearing selection superseded by D-012; HOLD on quote, coupons, rig and motor receipt |
| [D-008](#d-008) | 2026-09-29 | Chassis / wheels | Wheel face: six framed spokes, 12-sided vented beadlock ring and a proud hex hub cap, after the builder's reference; hub on the D-007 interface | ACTIVE, HOLD with D-005 and D-007 |
| [D-009](#d-009) | 2026-09-29 | Chassis / wheels | Handed left/right tyres; D-008 wheel merged into chassis-v1 as the single wheel source | ACTIVE; full `check_layout.py` rerun pending |
| [D-010](#d-010) | 2026-09-29 | Chassis / axle/frame | Keyed single-print motor carriers join to split rails through J04 | ACTIVE for J04; bearing selection superseded by D-012; HOLD on fit coupons, full clearance rerun and physical rig |
| [D-011](#d-011) | 2026-09-30 | Chassis / nose (J07, J08) | Ball-transfer nose closed in CAD: caster screwed from below into seat inserts, sliding snap-retained touch cap on a constant nose, ESE22MV21 switch, screwed lid, J10-8 cable exit | ACTIVE; switch superseded by D-013; HOLD on received-caster measurement, coupons and physical tests |
| [D-012](#d-012) | 2026-09-30 | Chassis / axle | Select 688 ZZ, 8 × 16 × 5, from the OnlyScrews listing; revise paired-bearing seats | ACTIVE; HOLD on supplier stock/lot evidence, drawing/load data, fit coupons, clearance rerun and retention test |
| [D-013](#d-013) | 2026-09-30 | Chassis / nose (J08) | Nose contact sensing: DRV5055 linear Hall sensor and cap magnet, firmware trip at about 0.7 mm; replaces the D-011 ESE22MV21 switch; cap return springs | ACTIVE; HOLD on bench trip-point check and the PCB-10 J10-8 pin change |
| [D-014](#d-014) | 2026-09-30 | Chassis / rear keel (J09, J10) | Rear TCRT keel closed in CAD: M3 × 30 into crossmember inserts, bezel-and-shim TCRT retention with ±2 mm height, dovetail shoe, J10-10 disconnect at the keel with a route behind the crossmember | ACTIVE; HOLD on CH-020 breakout, CH-009/CH-010 materials, coupons and physical tests |
| [D-015](#d-015) | 2026-09-30 | Chassis / rear TCRT (CH-020, J09B) | Custom passive TCRT board that floats on the seated sensor; J10-10 becomes +3V3, GND, TCRT_OUT (ADC), LED_EN | SUPERSEDED by D-016 |
| [D-016](#d-016) | 2026-09-30 | Chassis / rear TCRT (CH-020, J09B) | No board: TCRT soldered to a GH4 lead that plugs into C3 J10-10; LED switch and load on PCB-10 | ACTIVE; HOLD on the PCB-10 J10-10 change and bench item 20 |
| [D-017](#d-017) | 2026-09-30 | Chassis / rear keel wear parts (CH-009, CH-010) | Recommendation: PETG for the wear shoe and the TCRT bezel; UHMW-PE tape on the shoe as an optional upgrade | RECOMMENDED; confirm after the item 20–22 tests |
| [D-020](#d-020) | 2026-09-30 | Chassis / nose springs (CH-066) | Industrybuying RS PRO 821245 selected for purchase; retain 9/6 mm installed gaps pending force and guidance tests | SELECTED; higher preload, cap force, buckling and hook retention unverified |
| [D-021](#d-021) | 2026-09-30 | Chassis / rear floor sensor (CH-020) | Bare Vishay TCRT5000 selected; Robu comparator module excluded from the designed keel interface | SENSOR SELECTED; supplier provenance, assembly fit and floor/cliff validation open |
| [D-022](#d-022) | 2026-09-30 | Chassis / fastener sourcing | Use best available supplier candidates after OnlyScrews checks; define J12/J13 nominal screw stacks | Superseded in part by D-023 |
| [D-023](#d-023) | 2026-09-30 | Chassis / fastener availability update | CH-035 and CH-038 reported available; CH-030/055/060 remain unsourced | Superseded in part by D-024 |
| [D-024](#d-024) | 2026-09-30 | Chassis / remaining fastener source leads | ACME low-head screw family and Dalloyed grub-screw family added as Indian quote/sample leads | OPEN; exact size/stock still to confirm |
| [D-025](#d-025) | 2026-09-30 | Chassis / mixed CSK fastener assortment | Mixed M3/M4/M5 kit may cover CH-038; M4 CSK does not fit CH-035 | CANDIDATE; kit source/material and fit unverified |
| [D-026](#d-026) | 2026-09-30 | Chassis / battery and ballast CAD (CH-022, CH-038, J12) | BOM and CAD reconciled: 1.1 mm cell gap, countersunk CH-038 seat, 350 mm TCRT mass note; chassis-v1.step rebuilt | ACTIVE; PCB-01 height, received-screw fit and full `check_layout.py` rerun open |
| [D-027](#d-027) | 2026-09-30 | Chassis / purchased-part models (CH-017, CH-018; J08A/J08C) | Vendor STEP for the A21 and a board-file STEP for the #3297 replace boxes; A21 ears trimmed, lead soldered, nose lid/cap reworked for the real package | ACTIVE; received-unit fit, ear trim and lead strain relief open |
| [D-028](#d-028) | 2026-10-01 | Chassis / battery tub interfaces (J11A, CN-05) | Shell opening sized to the hatch; front hatch bosses moved onto the tub front wall; bosses cut to Z 39.5 and the pack disconnect lifted 3 mm; IMU screw overlap recorded as accepted | ACTIVE; `check_layout.py` 116/119 (three D-027 failures open); boss and insert fit unproven |
| [D-029](#d-029) | 2026-10-01 | Chassis / nose lid (J08) | GP2Y soldered-lead reserve 3.0 to 2.0 mm, so the lid hump (top Z 57.6) clears the front panel's lift-off path | ACTIVE; lead bend in 2 mm to confirm at assembly |
| [D-030](#d-030) | 2026-10-01 | Chassis / frame fasteners, pack restraint, driver mounts (J05, J06, J11A, J11B, J12, J13, J15B, J16; CH-030, CH-055, CH-060) | J05/J06 inserts moved into the rail tongues; all frame, hatch and driver hardware modeled and added (CH-073–CH-082); pack strapped to the hatch; DIN 7984 → ISO 7380; set screw = M3 × 3 faced to 2.5 | ACTIVE; HOLD on coupons, strap/foam source and physical tests |
| [D-031](#d-031) | 2026-10-02 | Chassis / driver boards (J15B), inline motor pairs, motor face screws | #3297 boards turned long side along Y at X 38.5–56.3, posts at X 41.05; inline pairs re-placed; face-screw heads modelled as ISO 7380 domes; `check_layout.py` 119/119 | ACTIVE; supersedes the D-030 J15B layout; post coupon and received-board fit open |
| [D-032](#d-032) | 2026-10-02 | Chassis / main fuse holder (CH-028) | Inline Littelfuse 0FHA0001ZXJ ATO holder on a printed front-deck bracket above the +Y channel; the old channel envelope could not hold any ATO fuse | ACTIVE; CH-028 HOLD for an India source |
| [D-033](#d-033) | 2026-10-02 | Chassis / frame print units and hub cap (J03, J05, J06, J16; CH-001, CH-012, CH-058, CH-059, CH-073–CH-075, CH-077) | Each frame end printed as one module (deck + rails + crossmember), removing J05/J06/J16 and ten screws and inserts; hub cap held by one central M3 into the tapped stub end instead of six M2 | ACTIVE; HOLD on module print orientation, junction coupons and cap retention; full `check_layout.py` not rerun |
| [D-034](#d-034) | 2026-10-03 | Body / audio speaker (BO-001; BO-002–BO-006 registered) | Speaker: Visaton K 50 WP 8 Ω (art. 2915), element14 India 1683894; body audio chain entered in the project BOM | ACTIVE; speaker SELECTED, not ordered; HOLD on received-part measurement and bench listen |
| [D-035](#d-035) | 2026-10-03 | Body / audio bench amplifier (BO-007) | SmartElex MAX98357A I²S breakout (Robocraze) as the bench amplifier until PCB-05 exists | ACTIVE; SELECTED, not ordered; bench only |
| [D-036](#d-036) | 2026-10-03 | Body / audio microphones (BO-012, BO-005) | Mic IC: Infineon IM73D122V01XTMA1, element14 India 4125831; four-mic array (two per ADAU7002 lane), not six | ACTIVE; SELECTED, not ordered; HOLD on PCB-06 layout and the array tap test |
| [D-037](#d-037) | 2026-10-03 | Body / microphone mounting (BO-005, BO-006, BO-013, BO-014) | Mic boards mount on gasketed shell bosses with two M2 thread-forming screws and a soldered GH lead, not on the frame | ACTIVE; DESIGN; HOLD on boss coupon and PCB-06 layout |
| [D-038](#d-038) | 2026-10-03 | Power boards (PCB-01, PCB-03, PCB-10; CH-017, CH-023, CH-041–CH-043; CH-083–CH-086 registered) | PCB-03 drive feed re-specified for the DRV8833: SMBJ8.5A bus TVS, VM entry, AND-gate sleep, latched FLT, INA181 feed monitors; TIFPS0629 bench acceptance window; 04-pcbs home and board register; PCB-12 assigned to the C2 head carrier | ACTIVE; DESIGN; HOLD on TIFPS0629 bench acceptance and MOT3001 winding R/L |
| [D-039](#d-039) | 2026-10-04 | Harness (W01–W39, J-PK, J2-1, J3-1, J3-4, J8-1; CH-025–CH-027, CH-041, CH-042, CH-083; HN-001–HN-010 registered) | Fused pack feed split at butt splices beside the fuse (W04, J2-2 deleted); J-PK is the isolator; NTC break is a JST SM 2p in the +Y channel; Micro-Fit+ only on AWG16/18 UL1061, Micro-Fit 3.0 on AWG22, pre-crimped GH; J3-4/J8-1 to Micro-Fit 3.0; full wire list, pinouts and service breaks in 05-harness | ACTIVE; DESIGN; HOLD on housing PNs, crimp qualification and the first harness build |
| [D-040](#d-040) | 2026-10-04 | Charge path (PCB-02, PCB-13 registered; CH-041, HN-003; BO-015–BO-017 registered) | Charge inlet moves to a panel-mounted board PCB-13 (GCT USB4140, TVS2200, ESDA25W, STUSB4500, input P-FET) in a pocket that takes any compliant plug; charger straps closed: D+ tied to D−, BATP sense, TS 8.45 k / 324 k for 0–50 °C, 20 V-rated input | ACTIVE; DESIGN; HOLD on schematic, NVM image and bench CP-01 to CP-14 |
| [D-041](#d-041) | 2026-10-04 | Body / power button; E-stop removed (BO-018 registered; CH-041, CH-042, CH-046, HN-001, HN-004; W40, J2-9; W22, J3-7, W38 removed) | No E-stop: the rear red mushroom becomes the momentary power button (LTC2954 `PB`, GH2 `J2-9` on PCB-02's +Y edge, 10 k wetting pull-up); a press also resets `SYSTEM_ARM`, so it stops the motors in hardware; the latching NC IDEC XA1E is replaced by a 16 mm momentary 1NO mushroom in the same well | ACTIVE; DESIGN; HOLD on the received part's fit in the well and bench PB-01 to PB-06 |
| [D-042](#d-042) | 2026-10-04 | Body / compute retention and cooling (BO-033–BO-042; CH-084; W41, J9-4) | Pi 5 screwed to a vented three-point compute tray (rear −Y lug, front −Y column, rear +Y block); Active Cooler on its push pins with tip keep-outs; BO-040 2-wire 4010 side intake fan on a +Y frame web, switched on/off by Pi GPIO24 through a MOSFET on PCB-09 (`J9-4`, `gpio-fan`); +Y shell grille and collar, rear-panel vent slots, open floor as the outlet | ACTIVE; fan size and position superseded by D-043; HOLD on the bench thermal test, the AR-61 noise check, CR-02 and coupons |
| [D-043](#d-043) | 2026-10-04 | Body / enclosure fan vs mic ports (BO-040, BO-041; W41) | The +Y enclosure fan shrinks from a 4010 to the purchased 3010 hydraulic model and moves to X 17.5, Z 107, midway between the +Y mic ports: grille edge 24.1 mm from FRONT_L (was 14) and 25.9 mm from REAR_L; mic array unchanged | ACTIVE; DESIGN; HOLD on measured mounting holes, the bench thermal test and the AR-61 noise check |
| [D-044](#d-044) | 2026-10-04 | Body / head yaw stage (BO-043–BO-050, BO-056–BO-062; PCB-08/14; W37/W42/W43) | 61810-2Z bearing cartridge, 1:1 printed scissor spur pair, ±62° hard stops and FFC clock-spring cassette | ACTIVE; DESIGN; HOLD on received parts, coupons and B1/B4/cassette tests; D-047 changes its servo |
| [D-045](#d-045) | 2026-10-05 | Body / service-panel internal frames (BO-022, BO-023, BO-053; BO-031; BO-063 registered) | Internal panel frames printed as part of the shell, not bonded; bosses lengthened to 7.1–7.7 mm with M3 × 6 heat-set inserts for the M3 × 8 machine screws | ACTIVE; DESIGN; HOLD on the panel-boss coupon and the shell print |
| [D-046](#d-046) | 2026-10-07 | Head / pitch and roll actuators (HD-001 registered; RP-01 `ACT-01` overridden for pitch/roll) | Feetech STS3045M (metal gear, coreless, 34.8 g) for pitch and roll, replacing the XC330-M288; fastest pitch moves capped at 70% speed; head rail setpoint must rise above the servo's 4.8 V minimum; yaw servo and bus protocol open | SELECTED; HOLD on head CAD re-fit, rail setpoint, bench B1/B4 |
| [D-047](#d-047) | 2026-10-07 | Body / yaw servo (BO-043) | Waveshare ST3215-HS on a 12 V yaw-only rail on PCB-03 replaces the D-044 XC330-M181-T: speed margin first, one Feetech protocol with D-046; STS3250 fallback on lash, XC330-M181 if no Feetech case fits | SELECTED; provisional case fit found; HOLD on mount/hub integration, rail and bench B1/B4 |
| [D-048](#d-048) | 2026-10-07 | Body / ST3215-HS yaw integration and compute-stack shift (BO-043, BO-056, BO-061; CH-084 PCB-09, CH-086 PCB-10, PCB-04; W15) | HS on the true horn axis, horn up, case to -X, 7.6 mm lower, clamped by four M2 screws to a frame ring; Pi, cooler, tray bosses and PCB-09 move +10 X / -6 Y; tray +Y edge to Y 23.5; C3 Z 92 header row repacked | ACTIVE; CAD packaging screens clean; HOLD on a matching plug, torque/gear proof, received HS, head re-balance and bench B1/B2/B4 |
| [D-049](#d-049) | 2026-10-08 | Head / STS3045M pitch and roll installation (HD-002–HD-007; head v1 CAD, A0, body v1 hand-off) | Roll servo on an ear plate driving the spindle through a goBILDA 25T-to-Ø6 coupler, rear bearing forward; pitch servo on the pitch frame with its horn screwed to a widened +Y yoke leg; CF-filled yoke legs; rear trim off-axis; A0 re-solved | ACTIVE; CAD and checks complete; HOLD on received horn/coupler fits, the CF leg coupon and bench B1/B4/B6 |
| [D-050](#d-050) | 2026-10-09 | Head / yoke legs and turntable restyle (M011-Y, M012; head v1 CAD, mass tree, body v1 hand-off) | Both yoke legs become one faceted design inscribed in the D-049 free corridor (plinth, waist, arm), replacing the +Y leg's stair-stepped raster outline, ledge and box foot; disc rim tapers R62.5 to R58.5; opaque presentation model | ACTIVE; CAD and checks complete; HOLD on the CF leg coupon and print orientation |
| [D-051](#d-051) | 2026-10-10 | Head / passive pitch pivot and yoke-leg joints (HD-008–HD-011; M011-Y, M012; head v1 CAD, mass tree, body v1 hand-off) | −Y pivot becomes an MR106ZZ in the −Y leg pad, a flush printed retainer and a Ø6 D-shaft pin into a D-bore boss on the pitch frame; each leg plinth keys over a block on the disc top and takes two M2 screws from its inner face | ACTIVE; CAD and checks complete; HOLD on received bearing/D-shaft fits, a seat and key coupon, and bench B6 |
| [D-052](#d-052) | 2026-10-10 | Body + head / yaw cable path (BO-045, BO-050, BO-058, BO-062; M012; W37/W42/W43) | The cassette FFCs enter the drum through a full-height slit at 0° (wraps 150°/90°), fold once and plug into three vertical PCB-14 joiner boards held in rotor posts under the hub shoulder; the head FFCs rise from their upper ZIFs through a Ø21 disc bore into a 12.5 × 1.5 mm channel, demating with the disc on; hub bore R13.15, disc pilot R10.5–13 | ACTIVE; CAD and checks complete; HOLD on the ZIF selection, an FFC fold mock-up and the cassette bench test |
| [D-054](#d-054) | 2026-10-10 | Head / camera housing restyle (M019a; head v1 CAD) | The 46 mm crown and its hipped roof cap become a slim raked fin: the crown narrows to 40 mm with 3 mm top chamfers and keeps its flat top to X −24; the skin hood behind it rakes down at 35.5° to the roof, about 25 mm long instead of running back to X −78 | ACTIVE; CAD and checks complete |

Status words: `ACTIVE` is in force, `SUPERSEDED` names its replacement, and `HOLD` names the evidence that must arrive before dependent work is released.

---

## D-001

**2026-09-28 · Governance · ACTIVE**

**Decision:** from this date, `docs/03-build/` is the governing context. Every new decision, part selection, BOM change and CAD edit is recorded in `03-build/`, in the subsystem and version folder it belongs to, and logged in this ledger. `docs/02-prototypes/` (all RPs, including RP-03 locomotion and RP-06 CAD) is read-only reference. Where an RP document disagrees with `03-build/`, `03-build/` wins.

**Changed:** [README.md § Governing context](README.md#governing-context).

**Note:** chassis v1 CAD still reads purchased STEPs and the Layout 04 head from `02-prototypes/RP-06-cad` by path ([cad/README.md](01-chassis/v1/cad/README.md)). Reading them is allowed; moving or copying them is a `03-build/` change and gets its own entry.

---

## D-002

**2026-09-28 · Chassis / drive (CH-014) · SUPERSEDED by [D-003](#d-003)**

DFRobot FIT0521 (6 V, 34:1, 3.2 A stall) was briefly the working choice on budget. It was dropped the same day: TME India had stock, but DigiKey quoted a lead time of about 9 weeks, and the builder chose the in-India ThinkRobotics part instead. Its CAD and BOM changes were replaced by D-003.

---

## D-003

**2026-09-28 · Chassis / drive (CH-014) · ACTIVE, HOLD on receipt measurements**

**Decision:** the chassis v1 drive gearmotor is the **ThinkRobotics MOT3001-6V230RPM**, "25mm DC Metal Encoder Gearmotor", 6 V / 230 rpm variant, ₹1,179.99, in stock ([product page](https://thinkrobotics.com/products/25mm-encoder-dc-metal-gearmotors)). It is a generic JGA25-370 with an 11 PPR Hall encoder on the motor shaft. It replaces the Pololu #4804 (about ₹5,956 in India) and the FIT0521 (D-002), and was chosen by the builder on cost and in-India availability.

**Performance accepted:** this motor **does not meet** the RP-03 drive gate ([gearmotor-sku-decision.md](../02-prototypes/RP-03-locomotion/gearmotor-sku-decision.md)): at least 159.2 rpm at 0.110 N·m (0.70 m/s heavy launch on the Ø84 wheel), and at least 0.220 N·m stall. ThinkRobotics does not tabulate the 230 rpm variant. The figures below are linear-motor estimates (`E`) from the family data: about a 6,000 rpm base, 1.8 A stall at 6 V, and stall torque about 0.08 kg·cm per unit of ratio. They imply about 26:1 and about 2.1 kg·cm stall.

| Case, 6 V motor | Speed at 0.110 N·m heavy launch | Speed at 0.063 N·m nominal load | Stall torque |
|---|---:|---:|---:|
| 6.0 V at motor | about 107 rpm (0.47 m/s) | about 160 rpm (0.70 m/s) | about 0.20 N·m (fails ≥0.22) |
| 5.3 V at motor (nearly empty pack) | about 80 rpm (0.35 m/s) | about 133 rpm (0.58 m/s) | about 0.18 N·m |

**Consequence:** plan chassis v1 around a **reduced drive envelope** until measured: about 0.5 m/s cruise at nominal load, gentler launch and acceleration limits, and a stall margin below the 2× rule. Heavy-mass launch, threshold climbing and slope hold at full ballast are the tests most likely to fail. The 0.70 m/s RP-03 target is not claimed for v1. Good side effects: 1.8 A stall suits the DRV8874 and the 5 A bench supply, and 11 × 26 × 4 ≈ 1,140 encoder counts per wheel revolution is enough for creep and hold.

**Motor availability:** no motor is currently on hand. A MOT3001-**6V170RPM** was considered as a possible lower-speed bench stand-in, but it has not been procured and is not available for fit, encoder or firmware tests. The selected MOT3001-6V230RPM units also remain to be ordered.

**CAD changed** ([body_chassis_model.py](01-chassis/v1/cad/body_chassis_model.py)):

- The motor is modelled parametrically from the ThinkRobotics/JGA25 drawing (no vendor STEP): Ø25 gearbox (21 mm assumed; the drawing gives 19–27 mm by ratio), Ø24.4 × 31 mm can, encoder board with a rearward 6-pin connector, Ø7 × 2.5 bushing boss, and a Ø4 D-shaft 12.0 mm from the faceplate (was 12.5 on the #4804) with an 8 mm flat. Faceplate to encoder end is about 61 mm (was 66.5).
- Axle flange, 2 mm diaphragm, 608 pair and stub shaft are unchanged. The shaft engages the stub for 8.0 mm (was 8.5).
- Face screws keep 2 × ISO 10642 M3 × 8 at ±8.5 mm. That pattern and the 5 mm tapped depth are **assumptions**; the drawing does not give them.
- The motor pigtail reserve is extended rearward to X −21 to meet the connector.
- Mass register: MOTOR_L/R 101 g at |Y| 39.2 → 110 g at |Y| 40.2. The 110 g is the NFP-JGA25-370-EN figure for this platform; ThinkRobotics lists a 130 g shipping weight. Weigh on receipt.
- Check results: _pending the full rerun_.

**BOM changed:** CH-014 in [BOM.csv](BOM.csv) and [01-chassis/v1/BOM.md](01-chassis/v1/BOM.md).

**Release holds and next actions:**

1. Order two MOT3001-6V230RPM plus one spare.
2. When a motor is received, measure face hole spacing, thread and depth; gearbox length; shaft protrusion and D-flat; connector position and cable exit; and mass. Verify those measurements against the CAD assumptions and update the model if anything differs.
3. Bench test on a current-limited supply: no-load speed and current at 6.0 V and 5.3 V to confirm the winding and ratio; speed under a known 0.063 N·m and 0.110 N·m load; encoder counts per output revolution; a brief current-limited stall. Record the measured drive envelope here and set the firmware speed and acceleration limits from it.
4. Run the chassis heavy-launch, threshold and slope-hold tests at representative ballast early. If they fail, open a new entry. Fallbacks, in order: Pololu #4803 (₹5,956, passes with margin) or FIT0521 (TME India).

---

## D-004

**2026-09-29 · Chassis / wheels (CH-004, CH-005, CH-006, J14) · SUPERSEDED by [D-005](#d-005)**

**Decision:** the drive wheel is a PETG six-spoke rim carrying one of two tyres. The builder asked for a rugged look, a simple build, and one printed and one non-printed rubber option. A later entry picks one variant from test results.

- **Variant A, printed:** a TPU 95A tyre with two staggered rows of lugs. It is keyed to 12 ribs on the rim seat and clamped between an integral inboard lip and a bolt-on outboard ring by 6 × ISO 7380 M3 × 8 screws into heat-set inserts. The tyre can be changed without removing the wheel.
- **Variant B, bought:** three 70 × 5 mm NBR 70A O-rings stretched 5.7% into grooves on a one-piece rim. No hardware.
- **Spin index:** a paint-filled notch in one spoke instead of a separate inlay.

**Why:**

- **A smooth ring on a smooth rim was never a joint.** Positive keying plus side clamping (A), or a stretched seal in a groove (B), are the simplest retention methods that don't rely on glue.
- **The clamp ring makes the tyre serviceable in place** (CON-P01).
- **O-rings need no flexible printing at all.** They cover the case where the lab can't print TPU.

**CAD added:** the standalone [wheel CAD](01-chassis/v1/cad/wheel/README.md) (`wheel_model.py`, three STEP entries, `check_wheel.py`, 26/26 measured checks passing). It keeps the chassis Ø84 × 24 envelope, the R18 boss pocket and the Ø8 stub bore. **The chassis model and `chassis-v1.step` are not changed**, and still show the placeholder tyre. Mass at solid density: A 90.0 g, B 80.8 g, against 89 g in the chassis register.

**BOM changed:** CH-004/005/006 set to DESIGN. Added CH-048 (screws), CH-049 (inserts) and CH-050 (O-rings); only the chosen variant's hardware is bought.

**Unverified:** TPU print allowances (bore Ø73.6, width 19.3), O-ring cord thinning (estimated OD 83.7), loaded radius, grip, creep at stall, left/right OD match and runout. The stub-to-hub torque joint (J03) is still open; the R4 bore is a placeholder.

**Next actions:**

1. Confirm whether the 3D lab can print TPU 95A. If not, variant B is the only option.
2. Print one rim of each variant plus the tyre coupon. Measure loaded radius at about 1 kg, μ on S-TILE/S-LAM/S-RUG, stall-torque creep and runout.
3. Choose the variant in a new entry. Then port it into `wheel_assembly()` in the chassis model, replace `loaded_radius_matches_axle_height` with the measured radius, and rerun the chassis checks.

---

## D-005

**2026-09-29 · Chassis / motor interface · ACTIVE**

**Correction:** the builder has **no motor on hand**. A 6V170RPM unit had been mentioned as a possible bench stand-in, but it was not purchased or available for measurement. The 6V230RPM motor selection and reduced drive-envelope estimate remain the working choice; all motor fit and performance checks await receipt of hardware.

**Design direction:** continue chassis engineering from the supplier drawing and clearly labeled CAD assumptions. Put the uncertain face-hole/pilot/shaft interface in replaceable or adjustable parts so a mismatch does not force a complete frame reprint. The [motor interface sheet](01-chassis/v1/research/motor-interface-sheet.md) is parked, and the [mechanical checklist](01-chassis/v1/research/engineering-checklist.md) no longer includes a motor-measurement task.

**Limit:** an assumed interface can support a provisional CAD and fit print, but it is not evidence of physical motor fit, safe shaft coupling, or drive performance. Those remain unverified until actual hardware is assembled and tested. No motor-dependent part is marked physically passed by this decision.

**Next:** engineer the frame split and replaceable carrier/plate (J04/J01), then revise the axle stack and wheel hub with explicit assumption ranges and service access.

---

## D-005

**2026-09-29 · Chassis / wheels (CH-004, CH-005, CH-006, CH-050, J14) · ACTIVE, HOLD on lab TPU capability and grip/retention tests**

**Decision:** the builder chose the printed TPU tyre from D-004. It is the only modelled wheel. Three further changes come with it:

- **Tread:** the plain lugs are replaced by a chevron tread: 18 V-lugs 1.5 mm tall, bars at 40° to the axle, apexes on the tyre centre line. Below about 37°, the Vs leave gaps on the contact line and the wheel bumps 18 times per revolution; the check caught 18 of 72 angles open at 30°.
- **Outboard face, restyled to the droid's shell language** ([vision](../00-foundation/vision.md#character-and-visual-direction), RP-01 D-07 stepped panels):
  - six windows in a 1.5 mm stepped surround, leaving stepped spokes 10 mm wide at the root with a 6 mm crest;
  - a two-step hex hub;
  - a 12-sided beadlock-style clamp ring with a flat facing each screw.
- **Spin index removed:** no notch, no paint and no part. CH-006 is deleted.

Retention is unchanged from D-004: 12 seat ribs, an inboard lip, and a clamp ring with 6 × M3 × 8 button heads into heat-set inserts.

**Fallback, recorded here only (not modelled, no BOM row):** if the 3D lab can't print TPU 95A, use a one-piece PETG rim with three grooves, 5.4 mm wide and 2 mm deep, with a Ø74 bottom and Ø78 lands, at y −7.1 / 0 / +7.1 mm. Fit three **70 × 5 mm NBR 70 Shore A O-rings**, stretched 5.7%; the cord is 36% seated and about 83.7 mm OD mounted. No hardware; the O-rings roll off to replace them. If they creep in the groove, put a drop of CA glue in each groove. D-004 checked this geometry (all 12 O-ring check rows passed).

**CAD changed:** in the [wheel CAD](01-chassis/v1/cad/wheel/README.md), the O-ring model, the variants entry and the index were removed. The single entry is now `wheel.step.py`, and `check_wheel.py` passes 18/18. The checks now also cover spoke section, clamp-ring corners, hub cap and chevron contact continuity. Mass at solid density is 93.7 g per wheel, against 89 g in the register. The chassis model is still not changed.

**BOM changed:** CH-004 and CH-005 re-specified. CH-006 and CH-050 deleted. CH-048 and CH-049 are no longer marked as variant-only.

**Next actions:**

1. Confirm the lab can print TPU 95A (direct-drive extruder).
2. Print a rim, a clamp ring and a tyre coupon. Measure fit, loaded radius at about 1 kg, μ on S-TILE/S-LAM/S-RUG, stall creep and runout.
3. Port the wheel into `wheel_assembly()` in the chassis model. At the same time: remove the placeholder index inlay, update the mass register (+4.7 g per wheel) and the loaded-radius check, and rerun the chassis checks.

---

## D-006

**2026-09-29 · Chassis / wheels (CH-004, CH-048, CH-049) · SUPERSEDED by [D-008](#d-008)**

**Decision:** the builder found D-005's six stepped spokes too plain and supplied three reference wheels: automotive five-spoke rotor designs with swept, faceted, two-tone blades. The rim face now follows them:

- **Blades:** five blades, each leaving a whole flat of a pentagon hub. The straight leading edge sweeps 30°; the trailing edge kinks at R20 and flares, so each blade covers 48° at the rim and leaves a 24° window.
- **Two-level face:** each blade face is split by a ridge. The leading band stays at full height, and the trailing flank slopes 15° down, to about 4.3 mm at the flare corner. This gives two tones under light, and takes a two-tone paint finish if wanted.
- **Details:** a through-slot in each flare, and a round cap on the hub.
- **Clamp ring:** round, not 12-sided, so the face reads as one clean lip as in the references. It now uses **5** M3 button heads, one mid-window, matching the five blades.

Tyre, tread, rib keying and the O-ring fallback are unchanged from D-005.

**Why the numbers:**

- **15° flank, not 20°:** the wider flare would otherwise fall below 2.5 mm at its trailing corner.
- **Five screws still clamp the full bead:** the ring covers the tyre side by 2 mm all round.

**CAD changed:** `wheel_model.py` and `check_wheel.py` in the [wheel CAD](01-chassis/v1/cad/wheel/README.md). The spoke checks now cover the blade solid on its ridge, flank thickness ≥ 2.5 mm (measured 4.3) and the leading band at full height. **20/20 pass.** Mass at solid density is **88.5 g per wheel**, against 89 g in the register, so the D-005 register update is no longer needed. The chassis model is not changed.

**Print impact:** the rim still prints outer face down, because the hub cannot float over the inboard dish. The 15° flanks are then shallow overhangs and need tree supports.

**BOM changed:** CH-004 and CH-005 re-specified; CH-048 and CH-049 quantities go from 12 to 10.

---

## D-007

**2026-09-29 · Chassis / axle (CH-012, CH-015, CH-030, CH-051–CH-057; J01, J02, J03) · ACTIVE, HOLD on shop quote, fit coupons, axle rig and motor receipt**

**Decision:** the builder accepted the [axle stack](01-chassis/v1/research/axle-stack.md) architecture and its three choices: the bearing change, the turned one-piece stub, and designing around an absent motor. Per side, the stack is:

- **Stub.** One turned EN8 part carries torque and locates the wheel. It has Ø8 k5 bearing seats, a Ø4.05 bore on the motor's D-shaft (8 mm engagement), a DIN 916 M3 × 2.5 set screw on the flat, a Ø24 flange with three tapped M3, and a Ø10 spigot that centres the wheel.
- **Bearings.** Two **MR148ZZ** (8 × 14 × 4) in a bolt-on printed housing, held between a housing shoulder and a 1.2 mm aluminium cap. Four M3 × 18 screws pass through cap and housing into heat-set inserts in a 5 mm motor plate.
- **Motor alignment.** The motor floats on 0.3 mm of clearance at its pilot and face screws. The face screws are tightened last, through key slots, once the motor has aligned itself to the stub.
- **Wheel.** Three M3 × 6 screws through the web into the stub flange. Removing the wheel needs only those three screws.

**Why:**

- **The modelled stack was not buildable** ([axle-stack.md §1](01-chassis/v1/research/axle-stack.md#1-why-the-previous-stack-could-not-be-built-as-modelled)): no torque path motor → stub → wheel, no bearing retention, an over-constrained motor, and screw heads buried behind the bearings.
- **608ZZ does not fit.** A 608 pair is 14 mm wide, so it cannot sit inside the fixed Ø84 × 24 wheel together with a coupling and a flange.
- **A 678ZZ is not a substitute.** It is 8 × 12 × 3.5, not 8 × 14 × 4.

**Review holds from the proposal, and how the model now answers them:**

1. **Bearing designation** → MR148ZZ, not 678ZZ. CH-015 still needs the exact supplier article and drawing.
2. **Set screw breaking out of the stub end** → the stub now starts at |Y| 73 (1.5 mm off the motor pilot, in a 2.5 mm plate recess). The hole at 75.7 leaves 1.2 mm of steel to the end and 1.3 mm to the bearing seat. The M3 × 2.5 cup point sits flush with the Ø8.
3. **Edge margins** → four cap screws on the diagonals at R 12. The insert is ≥ 4.5 mm from the plate edges. The housing is Ø32, leaving 2.3 mm of wall outside each hole. The face-screw key paths now open into the bearing bore as slots at 0°/180°, instead of leaving a 0.2 mm skin. The slots sit off the vertical load line.
4. **Outward thrust on the inner rings** → still a k5 press fit plus Loctite 641; there is no room for a circlip. Required: 100 N outward hold, about 4× the load of lifting the robot by one wheel. Over 2 × π × 8 × 4 mm² of seat, that is 0.5 N/mm², far below any retaining compound's rated shear. **Not proven**: the axle rig includes a 100 N outward pull test.
5. **Screw-tip clash** → the wheel screws are M3 × 6, flush at the flange's inner face. A new check sweeps each rotating screw as a full ring: all are ≥ 1.55 mm clear.
6. **Fits** → all remain provisional until coupons (housing bore, spigot bore, inserts) and a quote.
7. **Shop quote** → still needed before ordering.
8. **Alignment proof** → axle-rig items: runout, drag and no-load current before and after tightening the face screws.

**Motor assumptions carried** ([D-005 motor interface](#d-005)): M3 face holes at ±8.5 mm, 5 mm deep; Ø7 × 2.5 pilot; Ø4 shaft 12 mm long with an 8 mm flat. The motor plate is the only part that encodes the face pattern. If the received motor differs, reprint the plate (or the carrier, J04). The stub's bore and set-screw position are the only turned features that depend on the shaft.

**CAD changed** ([body_chassis_model.py](01-chassis/v1/cad/body_chassis_model.py)):

- The flange/boss/diaphragm is replaced by `AXLE_MOTOR_PLATE`, `AXLE_BEARING_HOUSING` and `AXLE_BEARING_CAP`, plus the cap screws and inserts.
- New stub, set screw and wheel screws. The 608 STEP is replaced by parametric MR148 rings.
- The wheel pocket floor moves to |Y| 93, and the hub bore is Ø10 with 3 × Ø3.4 holes at PCD 16.
- Checks: `motor_face_joint_is_engaged` now requires ≥ 6 mm of shaft engagement. New checks: `axle_stack_is_retained`, `rotating_screws_swept_clear`, `bearing_model_is_mr148zz`. The old boss and 608 checks are removed.
- Mass register: frame +20.9 g, wheels −1.7 g each, axle row 64.4 → 44.0 g; all at the axle line.
- Check results: _pending the full rerun_.

**Interface for the standalone wheel CAD** ([D-005](#d-005)/[D-006](#d-006), [wheel model](01-chassis/v1/cad/wheel/README.md)): the wheel must now take the stub, not an Ø8 bore.

- Pocket R 18 to |Y| 93 (the web runs 93–97).
- Ø10 H7 bore through the web.
- 3 × Ø3.4 holes at PCD 16, clocked 30°/150°/270°.
- A flat seat for three ISO 7380 heads (Ø5.7) on the outer hub face.

The wheel model has not been changed by this entry.

**BOM changed:** CH-012 re-specified and set to DESIGN. CH-015 changed 608ZZ → MR148ZZ. CH-030 changed ISO 10642 M3 × 8 → DIN 7984 M3 × 6. Added CH-051 (housing), CH-052 (cap), CH-053 (M3 × 18 ×8), CH-054 (inserts ×8), CH-055 (set screws), CH-056 (M3 × 6 wheel screws ×6), CH-057 (Loctite 222/641).

**Next actions:**

1. Dimensioned stub drawing, then a quote from a local turning shop.
2. Print coupons: MR148 bore Ø13.90–14.10 in 0.05 mm steps; spigot bore Ø9.9–10.1; M3 × 4 insert holes; a plate section with counterbores.
3. Port the stub interface into the wheel model.
4. J04: the motor carrier and frame split.
5. Axle rig on receipt of the motor, with limits set before testing: runout ≤ 0.3 mm TIR, end play ≤ 0.1 mm, 100 N outward hold, drag and current before and after face-screw tightening, 200 reversals with set-screw paint marks.

---

## D-008

**2026-09-29 · Chassis / wheels (CH-004, CH-005, CH-048, CH-049, CH-058, CH-059; J14) · ACTIVE, HOLD with D-005 and D-007**

**Decision:** the builder chose this face over D-006's five-blade design. Two sessions had been restyling the wheel in parallel. D-006 was logged, but the CAD on disk became this design, and the builder confirmed this one. The design follows the builder's reference image: a 12-sided bolted beadlock, framed spokes, and a screwed hex hub cap. The tyre, chevron tread, rib keying and O-ring fallback are unchanged from D-005.

- **Spokes:** six framed spokes, 10 mm at the root, chamfered 1.5 × 1.5 to a 7 mm face, each with a recessed slot 3 mm wide and 2 mm deep. They run from a 26 mm hex hub, flats facing the spokes, to an inner ring with a 45° inner bevel. A 1 mm shadow groove sits between the inner ring and the clamp ring.
- **Clamp ring:** 12 sides, with six M3 × 8 screw flats (CH-048/049 back to 12 per robot) alternating with six recessed vent slots. The corners are chamfered and the flats are not.
- **Hub on the D-007 interface:**
  - the R18 pocket floor is at |Y| 93, over the bearing housing;
  - the web is 4 mm, with a Ø10 H7 bore on the stub spigot;
  - three Ø3.4 holes at PCD 16 (30/150/270° from +X) take the D-007 M3 × 6 button heads (CH-056) into the stub flange.

  Inside the pocket the spokes shrink to the 4 mm web, and the slot floor there is 2 mm.
- **Hub cap (new CH-058, CH-059):** a dark PETG hex cap, 26 mm across flats, with a faceted 16 mm boss. It stands 3 mm proud of the face (4.3 mm including screw heads), and a 1.9 mm-deep underside recess covers the three wheel screws. It is held by 6 × M2 × 6 thread-forming screws with 3 mm engagement. To remove the wheel: cap off, three M3 screws out, pull the wheel off the spigot.
- **Two-tone print:** rim and ring in light PETG, cap in dark PETG.

**Trade-offs:**

- The cap puts the hub 4.3 mm outboard of the wheel face, so the robot is **202.6 mm wide**, against the 205 mm target. Nothing on the chassis sits outboard of the hub.
- The rim and hub are 94.6 g per wheel at solid density, against 88.5 g for D-006 and 89 g in the register. The register needs +5.6 g per wheel when the wheel is ported into the chassis.

**CAD changed:** [wheel_model.py](01-chassis/v1/cad/wheel/wheel_model.py) and `check_wheel.py`. The checks add the D-007 pocket and turning flange clearance, the spigot bore, the 1.3 mm wall from bore to screw hole (D-007 geometry), wheel screws seated and ending at the flange face, the cap covering bore and screws, cap-screw engagement and seating, and a ≥ 0.5 mm cap wall (0.6). **23/23 pass.** The chassis model is still not changed; its `wheel_assembly()` keeps the D-007 plain rim.

**BOM changed:** CH-004 and CH-005 re-specified; CH-048/049 back to 12; CH-058 (hub cap) and CH-059 (M2 × 6 screws, 12) added.

**Records note:** the ledger has two entries numbered D-005, "Chassis / wheels" and "Chassis / motor interface", so `#d-005` links resolve to the first. Renumbering one is left to the builder, because D-007 links to the motor-interface D-005.

**Next actions:** the D-005 coupon adds the cap fit, the M2 pilot and strip torque, and the cap recess over real M3 heads. Port the wheel into `wheel_assembly()` together with the D-005/D-007 follow-ups: mass register, loaded radius, and the rotating-screw sweep, which must now include the cap.

---

## D-009

**2026-09-29 · Chassis / wheels (CH-005, J14) · ACTIVE; full `check_layout.py` rerun pending**

**Decision:** the builder asked for a second tyre and for the D-008 wheel to be merged into the chassis-v1 CAD.

- **Handed tyres.** The right wheel is the left one turned round. With identical tyres, the right chevrons would point backward relative to travel. The right tyre is now the left one **mirrored**, so on the robot both chevrons lead forward, apex at the top toward +X (tractor convention). The chevron was flipped to lead forward on the left as well. Rim, clamp ring, hub cap and hardware are symmetric and identical on both sides. CH-005 becomes one left and one right tyre; they are not interchangeable.
- **Merged into chassis-v1.** [`wheel/wheel_model.py`](01-chassis/v1/cad/wheel/wheel_model.py) is now the single source for the wheel. `wheel_assembly()` in [`body_chassis_model.py`](01-chassis/v1/cad/body_chassis_model.py) places its `mounted_leaves(side, …)` and keeps D-007's stub and set screw. A new `_check_wheel_interface()` stops the build if the wheel's hub constants drift from the D-007 ones: pocket, bore, spigot, flange, and screw PCD, length, head and angles. The placeholder tyre and rim and the spin-index inlay (and its constants) are gone.

**Checks:**

- **Wheel alone:** `check_wheel.py` 24/24. New: `both_tyres_lead_forward_when_mounted` measures +7.0 mm on each side, and an un-mirrored right tyre reads −7.0, so the check discriminates.
- **Wheel on the chassis:** the new targeted script [`check_wheel_on_chassis.py`](01-chassis/v1/cad/wheel/check_wheel_on_chassis.py). `check_layout.py` assumes an axisymmetric wheel and treats its solids as the swept volume, which is no longer true. So every rotating part except the rim and the (axisymmetric) stub is swept as a revolved envelope, and the rim is turned through its 60° period in 5° steps. **All clear of the 1.5 mm running gap:**
  - rim ≥ 3.05 mm through 60°, to the bearing cap;
  - tyre 3.6 mm to the wheel-arch trim;
  - hub cap, ring screws and cap screws are further away;
  - the tightest are D-007's own parts: stub 1.5 mm to the bearing cap, set screw 1.53 mm, wheel screws 1.65 mm.

  Wheel on stub: 3 screws, 2.0 mm of thread each in the flange, no internal overlaps.
- **`check_layout.py`:** its `rotating_screws_swept_clear` count goes 8 → 32. The full run was **stopped at 42 minutes by the builder's choice** (normally about 10 min; the lugged tyre slows its whole-robot boolean sweeps). **It has not been rerun**, so its other wheel-dependent rows (track from the rim centre, loaded radius, connector/power clash maps) are unverified. Rerun it with the frame-split work.

**Mass register:** WHEEL_L/R 87.3 → 92.5 g (the wheel without the D-007 screws, which are counted with the axle), CoM kept on the wheel centre (in fact about 1 mm outboard).

**Not updated:** `body-chassis.step` (whole robot, gitignored, about 0.5 GB) still shows the old wheel until it is regenerated. `chassis-v1.step` is rebuilt.

**Next:** rerun `check_layout.py` in full; the D-005/D-008 print coupons; print one tyre of each hand.

---

## D-010

**2026-09-29 · Chassis / axle and frame (CH-001, CH-015, CH-060, CH-061; J02, J04) · ACTIVE; HOLD on printer/material coupons, clearance rerun and axle rig**

**Decision:** select the manufacturer article NMB L-1480ZZ (8 × 14 × 4 mm, MR148ZZ size) and define J04 as a removable, keyed carrier-to-rail joint. Use one printed carrier per motor side, combining the 5 mm motor plate and its front/rear cheeks; keep the bearing housing and retaining cap separate. Each carrier keys into the front and rear rail ends and clamps with two DIN 7984 M3 × 8 screws at each end, into 6 mm M3 heat-set inserts in the rails.

**Why:** this creates a modeled structural load path from the bearing housing through the motor plate/cheeks into both longitudinal rails while retaining independent wheel axles. The crossmembers span left-to-right at the front and rear; there is no axle shaft across the centreline. Keys set the carrier position so the screws clamp rather than locate it.

**CAD changed:** `body_chassis_model.py` fuses each motor plate with its two cheeks into `AXLE_MOTOR_CARRIER_L/R`; rail ends now contain 2.0 × 3.0 × 2.5 mm keys/pockets, two axial insert bores and tip relief per end. The model includes the eight J04 screws/inserts. `check_layout.py` now measures the gearbox seat and bearing housing against the carrier label. The README, checklist, axle-stack plan and BOM were updated.

**Nominal joint:** key pocket has 0.2 mm per-side and 0.7 mm end clearance; screw axes are at Z 38/48 mm, Y ±54 mm front and ±58.5 mm rear. Rail insert pilot is Ø4.3 × 6 mm. These are coupon starting values, not final process compensation.

**Bearing source:** NMB's [official L-1480ZZ page](https://nmbtc.com/parts/l-1480zz/) confirms the 8 × 14 × 4 mm article, 819 N dynamic rating and 386 N static rating. Official CAD is offered through PARTcommunity; retrieving its drawing/CAD and confirming the supply lot remain release actions. Ratings are catalog values and do not certify the printed housing, axle arrangement or retaining-compound joint.

**Verification:** a focused source-geometry check found no positive-volume intersection across the carrier, rail, screw and insert solids. This does not prove strength, print fit or fatigue. The latest wheel-on-chassis sweep was attempted but interrupted after several minutes before it produced results; the pre-J04 D-009 sweep remains the last complete nominal result. Full `check_layout.py` remains pending.

**Physical pass targets:** axle datum deflection ≤0.25 mm under 31 N radial and 8 N lateral service loads; ≥1.5 mm running gap at those loads using measured print stack; proof at 62 N, 16 N and 0.8 N·m with no cracks/insert movement and ≤0.10 mm residual set. Each insert coupon must hold 100 N axially. Axle rig limits remain runout ≤0.30 mm TIR, end play ≤0.10 mm, 100 N inner-ring retention for 10 s with <0.10 mm movement, current change within max(0.05 A, 10%) after face-screw tightening, and 200 low-speed reversals.

**Next:** retrieve the NMB technical drawing/CAD and confirm a lot; print bearing, insert and J04 key coupons after printer/material selection; rerun the current wheel sweep and full layout checks; build the side-specific axle rig when the real motor and turned stub are available. No physical test has passed yet.

---

## D-011

**2026-09-30 · Chassis / nose (CH-002, CH-003, CH-007, CH-019, CH-031–033, CH-062–064; J07, J08) · ACTIVE; HOLD on received caster, coupons and physical tests**

**Decision:** close the ball-transfer section's blocking CAD items from the printability and service-access review in one change, in [`body_chassis_model.py`](01-chassis/v1/cad/body_chassis_model.py). The [joint register](01-chassis/v1/joint-register.md) J07/J08 entries carry the details.

**Changes, by the builder's to-do numbering:**

1. **Caster fastening (J07A).** The three M3 screws used to end 3 mm into Ø3.2 clearance holes and held nothing.
   - Pololu's drawing 2691 shows a 2.7 mm web with Ø6.3 counterbores from the ball side. The imported STEP lacked them, and the model now cuts them.
   - The screws are now 3 × ISO 7380 M3 × 8 (CH-031), driven from below into 3 × CNC Kitchen M3 × 5.7 inserts (CH-063). The inserts go in Ø4.0 bores in a pod seat thickened from 3 to 6 mm.
   - Result: 5.3 mm of thread engagement, and the heads sit 0.43 mm off the ball.
   - The GP2Y now rests on the seat top (Z 35), so its rails are gone. No reclocking was needed.
   - The old `ball_screws_engage_flange` check is replaced by `ball_screws_thread_into_seat_inserts`. It needs ≥ 4.5 mm of shank inside a coaxial insert that sits in the seat.
2. **Touch cap (J08B).** The cap could only travel about 0.7 mm before it jammed on the raked prow, so the 3 mm switch travel was not real.
   - The nose is now a constant octagonal section from X 122.5 to the face. The cap's 0.5 mm running gap is now true: it measured 0.41 mm before.
   - The 0.5 mm flexures are replaced by two 2.0 × 16.5 mm vertical snap fingers with 0.8 mm hooks in flank slots, at about 2.2 % strain for a 1 mm spread.
   - The cap slides 3.0 mm and stops on the pod face. It slides off forward.
3. **Pod sliver.** The 0.40 mm skin sat at the ear slot's front end, where the old taper began at the slot.
   - The belt now holds full width to X 121.0, and a chamfer wedge outside the ear window is removed.
   - The slot's outer edge cannot move in to Y 21.5: the GP2Y ear flange measures ±22.25 mm, and the slot must stay full height so the sensor can lift out.
   - The same pass found an older open slit: the 15.5 mm pocket broke through the upper chamfer at Z 47–49 behind the belt, X 95–109. The pocket now narrows at 45° above the pod screw heads, to |Y| 12.3.
4. **Lid retention (J08C).**
   - A rear tongue drops into a pod-wall groove that is open forward.
   - The shell band sits 0.5 mm over the lid.
   - One M2 × 8 countersunk thread-forming screw (CH-062) goes into a pod boss at (124.6, −11.8).
   - Official removal: cap off, screw out, slide the lid 11 mm forward, lift.
5. **Cable exit.** The J10-8 route is modelled as harness reserves:
   - a round-cornered 6 × 3 mm slot at Z 32–35 through the pod back wall, with a 1 mm flared mouth;
   - a floor trough, plus a groove for the switch pair;
   - a run under the crossmember;
   - a new Ø5 bore through the crossmember and deck at (86, −31);
   - a riser beside the speaker cavity into the sensor trunk, and a drop to C3 J10-8 below the compute tray.

   No grommet.
6. **Switch (CH-019).** Panasonic ESE22MV21 detector switch: 4.25 mm full travel, 290 mN max ([datasheet](https://industrial.panasonic.com/cdbs/www-data/pdf/ATB0000/ATB0000C12.pdf)). It sits on an 8 × 6 × 0.8 carrier board (CH-064) in a floor recess. The lever tip sits 0.2 mm off the cap at rest. Tact switches were rejected because their travel is well under 1 mm.
7. **Cap clearance.** Fixed by the constant nose (item 2): the running clearance measures 0.50 mm.
8. **Inserts (CH-033, CH-063).** CNC Kitchen M3 × 5.7 standard, Ø4.0 hole and Ø4.6 knurl ([source](https://www.cnckitchen.com/blog/tips-and-tricks-for-heat-set-inserts)). The Ø4.0 bores now give 0.3 mm/side of interference; before, the modelled insert equalled the bore. The crossmember pod screws (CH-032) become ISO 7380 M3 × 8 with 5 mm of engagement.

**Verification (2026-09-30):**

- **Full `check_layout.py`: not rerun, by the builder's choice.** Its saved report still dates from 27 Sep, and the D-009/D-010 reruns also remain pending.
- **Nose checks:** the new [`check_nose_joints.py`](01-chassis/v1/cad/check_nose_joints.py) runs the J07/J08 rows of `check_layout.py` on the nose parts in about 30 s. All 12 pass:
  - thread engagement;
  - insert interference;
  - flange seat;
  - no nose clashes;
  - travel reserve clear;
  - 3 mm cap sweep with the hard stop and forward retention;
  - 0.50 mm running clearance;
  - nose width 40.6 mm;
  - shell notch clear;
  - CoM margin.

  `check_layout.py` itself parses but has not been run end to end with the new rows.
- **Service sweeps, body on:** [`check_nose_service.py`](01-chassis/v1/cad/check_nose_service.py) → [`nose-service.md`](01-chassis/v1/cad/generated/nose-service.md). Clear:
  - caster housing, ball, screws and base from below, with nothing else removed;
  - the three hex-key paths;
  - cap forward;
  - lid forward, then up;
  - sensor and switch up;
  - lid-screw driver;
  - every J10-8 reserve.

  The first run found three problems, all fixed and re-swept: the sensor was trapped by the new neck, the lid hit the front panel when lifted after 8 mm, and the cable drop hit the compute tray.
- **Printability** (DfAM tool, 4000 samples):
  - Pod: minimum wall 1.3 mm, was 0.40; 3.2 % support area printed seat face down.
  - Cap: 0.94 mm, the same bottom edge as before; 2.8 % support nose face down.
  - Lid: 3.4 % support on its side, against 41 % flat. Its lowest samples, 0.3–0.6 mm, are 45° knife edges along the split line through the chamfer, as before; they are edges, not skins.
- **Mass register** (hand-kept):
  - `BALL_NOSE_POD_SENSOR_CAP`: 15.9 → 18.7 g at (111.4, 0, 37.9), measured from the solids.
  - `CHASSIS_PRIMARY_FRAME`: −0.3 g for the bore.
  - Whole robot: 2590.1 g, CoM X +19.30 / Z 106.28 mm. a_tip is 1.78 against the 1.58 minimum, so the margin line passes (equivalent to X ≥ 17.1 mm at this height).
- **Exports:** `chassis-v1.step` is rebuilt. `body-chassis.step` is not regenerated.

**Still unverified:**

- the received #2691 web, counterbore, hole diameter and housing;
- insert pull-out in the pod seat and crossmember;
- the switch's ON point and force against the cap;
- snap-finger fatigue;
- lid screw strip torque;
- static load at 2.55 kg, drop and threshold climbing (set the pass numbers before testing);
- the timed body-on service dry run for the caster swap and the sensor swap;
- the J07B L-key reach at the dry run (about 12 mm to the GP2Y).

**Next:** measure the caster on receipt; print the pod, lid and cap in the stated orientations; run insert coupons, then the load, cap and service tests; write the caster and sensor service procedures from the dry run.

---

## D-012

**2026-09-30 · Chassis / axle (CH-015, CH-051; J02) · ACTIVE; HOLD on supplier availability, lot verification, drawing/load data, fit coupons, clearance rerun and retention test**

**Decision:** select the **688 ZZ, 8 × 16 × 5 mm** double-metal-shielded chrome-steel bearing listed by [OnlyScrews](https://onlyscrews.in/products/688-zz-deep-groove-ball-bearing-8x16x5) as the chassis design article. This supersedes the NMB L-1480ZZ/MR148ZZ selection in D-007/D-010; the axle-stack architecture, Ø8 stub and wheel interface remain. Use two bearings per side, four total.

**Reason:** the user selected a locally listed, standard 8 mm-bore bearing family after the previously selected L-1480ZZ could not be procured. The 688 ZZ uses the same 8 mm bore but has a larger 16 mm OD and 5 mm width, so its seat and positions must be changed in the CAD.

**Supplier evidence and procurement hold:** the listing gives ID 8 mm, OD 16 mm, width 5 mm, ZZ shields and chrome steel. It does not identify a manufacturer or publish a drawing, internal-clearance class or load ratings. At review, the page shows “Sold out” in its purchase panel while also displaying “In stock” in its descriptive copy. Treat current stock as unavailable/unconfirmed; obtain a confirmed orderable lot and preserve its markings and manufacturer data before physical qualification. No load rating is inferred from the page's generic claims.

**CAD change:** `body_chassis_model.py` now models 688 ZZ rings, OD radius 8 mm and 5 mm width. The pair occupies |Y| 76.51–81.51 and 81.51–86.51; the 0.01 mm inboard datum offset avoids a degenerate mirrored housing boolean. The Ø16 outer seat is coupon-tuned; bearings stand 0.16 mm proud of the housing's 86.35 mm outboard face for cap retention. The stub shoulder and wheel positions stay fixed. The set-screw station remains |Y| 74.8, giving 0.46 mm nominal from the Ø2.5 tap drill to the first bearing face. Verify this narrow land on the stub drawing and part. CAD checks assert the selected bearing and seat dimensions. Supplier STEP/drawing is unavailable, so the rings remain parametric placeholders.

**Fit and proof gates:** coupon the printed seat Ø15.90–16.10 mm in 0.05 mm steps; verify the actual Ø8 k5 shaft fit, race drag, shield clearance, runout and endplay with delivered bearings. Retain the inner rings by k5 plus Loctite 641 and pass the 100 N outward-hold test for 10 s with <0.10 mm movement. Rerun wheel-to-chassis clearance and full `check_layout.py`; inspect the nominal 0.46 mm edge clearance from set-screw tap drill to first bearing face on the turned-stub drawing. No physical fit, load or retention test has passed.

**Next:** monitor/order from the selected listing when available or obtain the same specified article from a confirmed supplier; request manufacturer, internal-clearance class, drawing and load data; then print fit coupons and run the motor-independent retention fixture. Motor-dependent axle testing remains separately blocked on motor receipt.

---

## D-013

**2026-09-30 · Chassis / nose (CH-007, CH-019, CH-064, CH-065, CH-066; J08B) · ACTIVE; HOLD on bench trip-point check and the PCB-10 J10-8 pin change**

**Decision:** replace the D-011 nose switch with contactless sensing. A TI DRV5055A3 linear Hall sensor on a small board in the pod seat reads a Ø2 × 1 N35 magnet in the touch cap, and the C3 firmware sets the trip point. Two small compression springs return the cap. Details: [nose-hall-board.md](01-chassis/v1/research/nose-hall-board.md).

**Why:** D-011 misread the Panasonic ESE22MV21 drawing. The "4.25 mm (2.05 mm)" figure means a full travel of **2.05 mm**; 4.25 is a height. The switch turns on at 1.5 ± 0.3 mm. A rigid 3 mm cap therefore either misses the switch or crushes it, with 0.25 mm of worst-case margin. Other options were considered and rejected:

- **DRV5033AJ Hall switch:** its worst-case thresholds (operate 3–12 mT, release 1–5 mT) need a 12:1 field ratio across the stroke. A small magnet over 3 mm gives about 7:1.
- **DRV5032ZE:** 20 Hz sampling, up to 75 ms latency.
- **Omron D2F hinge lever:** operating position tolerance of ±1.5 mm.
- **Foam pad, or a 2 mm stroke:** these depend on material properties or print tolerances.

The linear sensor with a boot-calibrated threshold has none of these limits. It also has no mechanical wear.

**CAD** ([`body_chassis_model.py`](01-chassis/v1/cad/body_chassis_model.py)):

- **Hall board:** 6.0 × 4.6 × 0.8 mm, standing in an open-top slot at X 126.6–127.4. The SOT-23 sensor sits in a notch through the seat's front face, centred at (Y 10, Z 32.6).
- **Magnet:** in a pocket in the cap wall, below the window slit. It clears the sensor by 3.1 mm at rest and 0.1 mm at the 3 mm stop.
- **Springs:** two spring pockets, Ø3.3 × 6 mm at Y ±3, Z 32.
- **Removed:** the D-011 floor recess, switch and lever.
- **Lead groove:** extended to the board.
- **Checks:** `check_layout.py` and `check_nose_joints.py` now check the magnet against the sensor at the stop, and treat the springs as compressible.

**Trip point** (on-axis field of the magnet, Hall plate 0.65 mm under the package top, still to confirm):

- 7.3 mT at rest, 15.7 mT at 1 mm, saturated at the stop.
- Firmware trips at rest + 5 mT and releases at rest + 3 mT.
- Trip is 0.71 mm of cap travel nominal, 0.50–0.95 mm over ±0.4 mm of gap and ±5 % Br. Release is at 0.48 mm.

**Interface change:** J10-8 becomes +5V, GND, GP2Y_VO, +3V3, HALL_OUT. The PCB-10 carrier must bring +3V3 and an ADC-capable pin to J10-8 in place of the switch pair.

**BOM:**

- CH-019 → DRV5055A3QDBZR.
- CH-064 → Hall board.
- New: CH-065 magnet, CH-066 return springs (2).
- CH-007 gains the magnet pocket.

The mass row is unchanged at about 0.3 g for the sensing parts.

**Verification (2026-09-30):**

- `check_nose_joints.py`: 12/12 pass. Magnet gap is 3.1 mm at rest and 0.1 mm at the stop, with no hits.
- `check_nose_service.py`: the Hall board lifts out once the cap and lid are off, and the cap slides off forward. The tool paths and the whole J10-8 route are clear. See [nose-service.md](01-chassis/v1/cad/generated/nose-service.md).
- `chassis-v1.step` is rebuilt.
- Full `check_layout.py` has not been run, by the builder's choice.

**Open:**

- the bench trip point (pass: 0.4–1.2 mm against a dial indicator);
- the spring rate, and whether the cap returns to its hooks from any position;
- the Hall plate depth from TI's package drawing;
- the PCB-10 J10-8 pin change and the C3 firmware threshold;
- magnet polarity at assembly.

---

## D-014

**2026-09-30 · Chassis / rear keel (CH-008, CH-009, CH-010, CH-020, CH-034, CH-067 to CH-072; J09A/B, J10A/B) · ACTIVE; HOLD on the CH-020 breakout, CH-009/CH-010 materials, coupons and physical tests**

**Decision:** close the rear TCRT keel's attachment, cartridge, cable and wear-part joints in CAD (to-do sections A–D). Joint details are in the [joint register](01-chassis/v1/joint-register.md#j09a--rear-keel-to-rear-crossmember).

**Why:** the keel screws ran into solid crossmember plastic, and the TCRT had no retention. The cable's Ø6 holes would not pass the 6.5 mm GH plug, and the old riser clipped them. The height shim overlapped the leads, and the shoe and guards were only fused to the keel.

**CAD** ([`body_chassis_model.py`](01-chassis/v1/cad/body_chassis_model.py)):

- **J09A, keel to crossmember:**
  - Four ISO 4762 M3 × 30 screws go into CNC Kitchen M3 × 5.7 inserts, fitted from below. Engagement is 5.5 / 5.7 mm; the insert length caps it below the 6–8 mm first asked for.
  - The rear pair moves from X −45.5 to −44.0. At −45.5 the insert left 0.2 mm of wall to the crossmember's rear face; the wall is now 1.7 mm (2.2 mm at the front face).
  - The counterbores are Ø6.5, and the crossmember's Ø6 cable bore is closed.
- **J09B, TCRT to keel:**
  - The pocket is open below the keel. The TCRT sits face down on the 0.6 mm end ledges of a printed bezel.
  - The leads go into a pass-through socket on the breakout, which sits in an open-top cavity behind the crossmember.
  - The height is set by 1 mm shims between the bezel and the keel belly (Z 12): two shims give Z 10, and zero to four give 12 to 8.
  - One M2 × 10 and a moulded pin fix the bezel. The old steel shim that overlapped the leads is removed.
- **Keel section:** the sensor flat widens to a 9.5 mm half-width, and a station at X −46 keeps the belly flat over the shim stack. The pocket wall at the chamfered edge goes from about 1.6 to 3.9 mm (to-do 15). The keel still has 1.0 mm of clearance in the 10.5 mm shell slot.
- **J10A, wear shoe:** it has a 2.5 mm dovetail tongue in a groove open at the front, held by one M2 × 6 thread-forming screw across the tongue.
- **J10B, guards:** both guard lips are now part of the bezel.
- **J10-10 cable:**
  - The disconnect is a top-entry GH4 on the breakout, so the keel comes off with four screws and one plug.
  - The cable leaves upward behind the crossmember, in the 7.6 mm gap to the shell wall, so neither the crossmember nor the deck needs a hole.
  - `harness_routes()` gains a 30 mm slack loop, a riser beside PCB-02 and a run over PCB-04, under the compute tray, to C3 J10-10.
  - A zip tie through a new lug on the crossmember's rear face gives the strain relief.
- **Breakout (CH-020):** still unselected. It is modelled as a 12.3 × 13 mm custom-PCB reserve; the 32 × 14 mm LM393 module does not fit.

**Mass:** REAR_SKID_KEEL goes from 12.0 g at (−39.9, 0, 20.4) to 19.6 g at (−40.2, 0, 22.4), with volumes measured from the solids. The model now reports 2605.1 g with the CoM at (19.07, 0.16, 105.87). The margin line needs X ≥ 17.08.

**BOM:** CH-008, CH-009, CH-010 (now one bezel), CH-020 and CH-034 are updated. New rows: CH-067 inserts (4), CH-068 shims (2), CH-069 to CH-071 M2 screws, CH-072 zip tie.

**Verification (2026-09-30):**

- New `cad/check_rear_keel.py` (about 2 min): 21 of 21 checks pass. It writes [rear-keel-checks.json](01-chassis/v1/cad/generated/rear-keel-checks.json). It covers:
  - no clashes in the keel stack;
  - screws in clear holes, with at least 5 mm of engagement;
  - hex-key paths from below;
  - shims clear of the TCRT;
  - the ±2 mm range;
  - sensor swap from below with the keel on;
  - the shoe sliding out forward;
  - the keel dropping 30 mm;
  - the board lifting out;
  - the J10-10 route clear of the frame, shell, electronics, body frame, panels, audio and sensors.
- `check_layout.py` keel rows are updated: the count-only screw row is replaced, and the shoe/guard backing rows follow the new parts. The pitch order (shoe 6.05°, guards 6.49°, keel 8.97°, sensor 10.43°), backing and CoM rows were run on their own and pass.
- `chassis-v1.step` is rebuilt.
- The full `check_layout.py` has not been rerun.

**Open:**

- to-do 8: select the CH-020 breakout and socket;
- to-do 12: choose the wear-shoe and bezel materials;
- E (print orientation and exports) and the rest of F;
- G (optical height on real floors, service timing, tip order).

---

## D-015

**2026-09-30 · Chassis / rear TCRT (CH-020, CH-071; J09B) · SUPERSEDED by [D-016](#d-016)**

**Decision:** CH-020 is a custom passive board. Its spec was removed by D-016. The TCRT5000 plugs into two 1 × 2 female headers underneath the board, and a top-entry GH4 on top is the J10-10 disconnect. The board has no comparator: the C3 node pulses the LED through a MOSFET and reads the phototransistor on an ADC1 pin. It subtracts ambient light, and any fault reads as a cliff.

**Why:** the builder asked for an off-the-shelf board first, and none fits the keel cavity of about 13 × 14.8 mm:

- the LM393 modules are 35 × 10 mm;
- the Soldered breakout is 22 × 22 mm;
- the Pololu QTR-1A fits, but carries a QRE1113 rated to 6 mm, against our 10 mm optical height, and cannot be swapped from below.

**Changes to D-014:**

- **Floating board:** the TCRT5000's standard 3.5 mm leads cannot stay engaged over ±2 mm in a socket on a fixed board. The board now rides on the fully seated sensor and moves with the shims (Z 20–25.6). A ledge at Z 19.8 only catches it while the sensor is out. The M2 × 5 board screw (CH-071) is dropped.
- **Socket:** the datasheet lead pitch is 5.5 × 2.54 mm, so the D-014 4-way block becomes two 1 × 2 strips, with the package's mounting clips between them.
- **Board size:** the GH4 moves to +Y 4.6 to clear the strips' solder joints. The board grows to 14.2 mm in Y, and the cavity to ±7.4 (keel side wall 2.1 mm).

**Interface change:** J10-10 changes from 5 V / GND / analog / digital to +3V3 / GND / TCRT_OUT / LED_EN. PCB-10 must provide an ADC1 pin with a 100 kΩ pull-up (fail-safe when unplugged) and a spare GPIO.

**CAD:** in `body_chassis_model.py`:

- the board, the two header strips and the moved GH4 are modelled;
- the cavity is widened and has a new ledge;
- the J10-10 service loop is widened to Y +7;
- the REAR_SKID_KEEL row goes from 19.6 to 19.4 g, without the M2 × 5 screw.

**Verification (2026-09-30):**

- `check_rear_keel.py` passes 23 of 23. The new rows cover:
  - the sensor stack clearing the keel at both ends of the J09 range;
  - the board sitting 0.2 mm above the ledge at the lowest setting;
  - the board riding on the seated sensor.
- `chassis-v1.step` is rebuilt.
- The full `check_layout.py` has not been rerun.

**Open:**

- confirm the emitter end against the placed STEP;
- check JST's BM04B land pattern against the 14.2 mm board edge;
- confirm a 5.0 mm dual-leaf header part;
- make the PCB-10 J10-10 change;
- bench item 20, which sets R2 and checks the fail-safe.

---

## D-016

**2026-09-30 · Chassis / rear TCRT (CH-020; J09B) · ACTIVE; HOLD on the PCB-10 J10-10 change and bench item 20**

**Decision:** there is no board in the keel. The TCRT5000's legs are soldered to a JST GH 4-way pre-crimped lead (AWG28, 350 mm) under heat-shrink, and the lead plugs into C3 J10-10. The LED resistor, the LED switch MOSFET, the gate pull-down and the phototransistor load/pull-up go on PCB-10. Spec: [rear-tcrt-lead.md](01-chassis/v1/research/rear-tcrt-lead.md). Supersedes [D-015](#d-015).

**Why:** the builder asked why a board was needed. Electrically it isn't: the D-015 board only carried a connector and a socket. The builder chose the simpler build over the two things the board gave:

- **Keel removal** now needs the sensor pulled out first, and J10-10 unplugged at PCB-10.
- **A sensor swap** replaces the sensor and its lead together.

**Changes from D-015:**

- **Keel:** the board cavity and ledge are removed, and the sensor pocket runs straight out through the keel top. This restores the full side walls. Keel body 14.64 cm³; the REAR_SKID_KEEL row is now 20.0 g at (−40.5, 0, 22.7).
- **CAD:** a heat-shrink joint envelope and the lead are modelled, and the slack loop goes back to Y −26 to 3.
- **J10-10:** pins are LED_A, LED_K, TCRT_OUT and GND. It is still a GH 4-way header, now wired to the PCB-10 circuit in the spec.
- **Fail-safe:** an open lead or dead LED reads high through the PCB-10 pull-up, which is a cliff.

**BOM:** CH-020 becomes the sensor and lead (CANDIDATE). CH-071 stays DROPPED.

**Verification (2026-09-30):**

- `check_rear_keel.py` passes 20 of 20.
- The new rows cover:
  - the sensor and lead dropping out below with the keel on;
  - the lead leaving through the keel top without touching it;
  - the stack clearing the keel across the J09 range.
- `chassis-v1.step` is rebuilt.
- The full `check_layout.py` has not been rerun.

**Open:**

- the PCB-10 J10-10 circuit;
- bench item 20 (sets R2, includes a motors-running pickup check);
- the joint sleeve fitting the 7.6 mm pocket on the real part.

---

## D-017

**2026-09-30 · Chassis / rear keel wear parts (CH-009, CH-010; J10A/B) · RECOMMENDED; confirm after the physical tests**

**Recommendation:** print the wear shoe and the TCRT bezel (with its guard lips) in **PETG**. The builder asked for a recommendation and delegated the choice.

**Why PETG over PLA:**

- **Impact:** the 1.5 mm guard lips and the shoe take floor strikes on a tip. PETG bends where PLA snaps.
- **Screws:** both parts carry thread-forming M2 screws (CH-069, CH-070), and PLA tends to crack around them.
- **Heat:** PLA softens around 55–60 °C and creeps under the screw clamp; PETG holds to about 75 °C.
- **Same print:** the keel is already a PETG candidate, so all the keel parts print in one material.
- TPU is excluded: its friction would grab the floor.

**Optional upgrade, not modelled:** if the shoe wears fast or drags on carpet or tile, add UHMW-PE tape (about 0.25 mm) to its sole, and thin the shoe by the same amount so the floor clearance and tip order stay unchanged. Nylon (PA) is the better printed wear material, if a printer that can run it becomes available.

**Changed:** CH-009 goes from OPEN to DESIGN, and CH-010's release check names PETG. J10A and J10B record the material. No CAD change.

**Open:** retention, abrasion, floor-strike and snag tests (items 21–22); revisit after the tests.

---

## D-018

**2026-09-30 · Chassis procurement and release scope · ACTIVE; receiving, fabrication and physical validation remain open**

**Decision:** record the user's settled **Pololu #2691 plastic-roller caster** and **Samsung INR18650-25R cells** as SELECTED. Correct the current motor row to SELECTED under D-003/D-005; purchasing the motor enables its receiving and load checks. SELECTED does not mean ordered, received, fitted or passed. Supplier-page stock and physical release checks are separate fields.

The canonical [BOM](BOM.csv) and [chassis snapshot](01-chassis/v1/BOM.md) contain the current supplier candidates, exact-match qualifications, and release checks.

**Recommendations, not new installed substitutions:** retain two DRV8874 carriers and the Sharp A41 for the current design; reject the OD8/free15/wire1 return spring; sample MISUMI C-UR3-10 if its quote is acceptable; buy the bare TCRT specified by D-016; consider Robokits MPU6050 for budget bench use. Ø3 × 1.5 mm N35, the purchased balanced 2S module and 5 A ATOF are conditional alternatives. Magnet pocket/threshold, IMU interface/mount, protection thickness and fuse/holder/current requirements must be resolved before adopting those changes. BF-013A compatibility is not established. No corresponding CAD substitution was made.

**Sourcing correction:** OnlyScrews BB688ZZ now shows in stock, superseding D-012's dated sold-out observation. Its maker/grade/load evidence, received fit and retention remain open. Common matched-size hardware and dowel links are recorded; DIN 7984 low heads, M3 × 18 button heads, M3 × 2.5 cup-point set screws, plastic thread-forming screws, selected 5.7 mm inserts and Loctite 641 retain exact-source work. Nearby articles are not approved substitutions.

**Test scope:** regulated supply-powered chassis tests may use a documented development controller, driver carriers, temporary harness and relevant sensor circuits before final system PCB fabrication. Verify intentional voltage/current limits, encoder logic, default disable, physical stop and braking/transient behaviour. Keep cells disconnected and use secured inert ballast for that scope. Battery-powered tests retain protected-pack construction, fuse/disconnect, thermal/charging and 8.4 V motor-control gates.

**Genuine new findings:** Samsung recommends >1 mm cell spacing against the current 0.2 mm CAD gap. The nose Hall note now treats trip values as predictions and records startup-pressed, missing-magnet and wire-break checks; shared 3.3 V supply does not make the ESP32-S3 ADC ratiometric. Define and verify diagnostic bias, ADC calibration and contact thresholds before functional release. These documentation corrections do not claim implementation or a passed test.

**Release audit:** nose/rear joint architecture is defined under D-011/D-013/D-014/D-016, while physical proof is open. Remaining detail gaps include J05/J06/J16, J11A/B, J12/J13 and J15A/B; purchased interfaces/stub drawing and print/process release are also pending. The saved full-layout baseline predates current source/checker changes. Stage gates are summarized in the chassis BOM; #4804 is superseded, not a current variant blocker.

**Custom PCB work:** a separate [04-custom-pcb folder](04-pcbs/README.md) (renamed `04-pcbs/` in D-038) now records the unreleased board work packages. No schematic, Gerbers or fabricated-board result is implied. Pre-existing edits to the chassis checker and engineering checklist were preserved. A malformed comma-delimited CH-012 release-check field was repaired while updating the BOM; installed quantities are unchanged.

**Verification:** thirteen review reports produced; supplier observations and documentation audited. No hardware purchase, receipt, CAD regeneration or physical PASS was performed in this review. Final CAD checks require the compatible pinned runtime and the release revision.

## D-019

**2026-09-30 · Chassis user selections: drivers, front range, nose magnet and pack protection · SELECTED; receiving and system validation open**

**Selected by the builder:** two Adafruit #3297 DRV8833 boards, one per motor, with both bridges paralleled within each individual board; Sharp GP2Y0A21YK0F from Robocraze; N35 Ø3 × 1.5 mm nose magnet; and Robocraze TIFPS0629 balanced 2S protection module, which the builder intends to buy. The builder reports the Sharp sensor is in stock and the only possible source/choice. These selections supersede prior alternatives and recommendations recorded in D-018 and the point reports.

**CH-064 conclusion:** retain the 6.0 × 4.6 × 0.8 mm custom nose Hall carrier. Its job is to hold the bare TI DRV5055A3, decoupling/filter parts and three-wire interface in the seat's specific slot. An adapter board can test the circuit on a bench but cannot satisfy the installed envelope. Layout/fabrication and contact/fault validation remain open.

**Engineering gates:** Adafruit/TI documentation supports the proposed bridge-parallel arrangement, but not an unconditional chassis current or thermal pass. Commission at a regulated 6 V supply with measured motor current, board temperature and braking/transient checks. The A21's 100 mm minimum range and 38.3 ± 9.6 ms measurement cycle do not satisfy the existing 50 ms stop-path budget once scan/control delay is included; revise and demonstrate the system timing/stopping distance while retaining the selected sensor. Measure actual A21 mounting datums before fit release. The 3 mm magnet changes the CAD pocket; check cap wall, pole, air gap and calibrated contact trip on the physical assembly. Robocraze's module listing gives a 48 × 20 mm footprint but does not establish its thickness or protection behavior; measure and qualify the received board before connecting cells. SELECTED or intended to buy does not mean ordered, received, fitted or passed.

**CAD and BOM:** update the source model, CAD checker names and project/chassis BOM to these choices. The model represents the A21 and Adafruit boards as nominal envelopes until received parts are measured. Generated STEP and reports are stale until the pinned compatible CAD runtime is restored and the affected checks are rerun. The 2.9 mm BMS height remains an unverified legacy placeholder, not a measured module dimension.

## D-020

**2026-09-30 · Chassis / nose return springs (CH-066) · SELECTED for purchase; installed behavior unverified**

**Decision:** the builder selected the Industrybuying listing for RS PRO 821245 stainless compression springs (pack of 10), with two required for the chassis. Published listing/datasheet values are OD 2.75 mm, 0.25 mm wire, 15.7 mm free length, 0.18 N/mm rate and 5 mm minimum working length. The builder said they are getting them; an order or receipt is not recorded.

**Geometry and force:** OD fits the current Ø3.3 mm pockets. Leave the seat floor and 9 mm rest / 6 mm full-travel gaps unchanged for the sample test. At those gaps, nominal pair force is approximately 2.41 N at rest, 2.67 N near the 0.71 mm Hall trip and 3.49 N at the 3 mm stop. At the stop, nominal length is 1 mm above the catalog minimum working length; tolerate as a limit to verify, not a proven coil-bind margin. The free spring is 15.7 mm and the seated gap is much shorter, so check seating, unsupported coil behavior/buckling, cap push force, return from intermediate positions and printed snap-hook retention. High force may make the nose less compliant than planned.

**CAD/BOM:** CH-066 is now SELECTED and the source spring envelope uses the actual 2.75 mm OD and 15.7 mm free-length data. The displayed model remains in its installed 9/6 mm envelope. No seat-floor redesign is made before sample measurements. Generated STEP and check reports remain stale pending the compatible pinned CAD runtime. Keep nose release gated on actual load and 3 mm stroke tests.

## D-021

**2026-09-30 · Chassis / rear floor sensor (CH-020) · SENSOR TYPE SELECTED; sourcing and physical validation open**

**Decision:** use a **bare Vishay TCRT5000 reflective sensor with its four individual leads** in the rear keel assembly. Solder the specified 350 mm AWG28 JST GH4 lead to the sensor under heat-shrink and connect it to J10-10. Do not use the Robu TCRT5000 IR Reflex Tracking Sensor Module (SKU 699619) as CH-020: it is a 5 V comparator/digital-output PCB with a different mechanical and electrical interface. D-016's no-board-in-the-keel design remains in force.

**Reason:** the bare sensor is the part envelope and pin-level interface specified by the existing keel CAD and D-016 lead assembly. The Robu module listing describes a 35 × 10 mm PCB and digital comparator output; it cannot fit the 7.6 mm sensor service pocket or connect directly to the four-wire analog/LED-drive interface.

**Procurement distinction:** the sensor type is settled, but no supplier order or receipt is recorded. The Robocraze pack-of-five listing remains a sourcing candidate; confirm that delivered parts are separate four-lead TCRT5000 packages and verify Vishay manufacturer provenance before representing them as genuine Vishay parts. A seller's generic TCRT5000 listing alone does not establish that provenance.

**Release checks remain open:** receive and measure the part, assemble and fit the sleeved lead in the real keel, then complete the documented 8/10/12 mm floor/edge, ambient-light, motor-running-noise and unplugged-fault checks. Selection does not mean the optical cliff function has passed; the nominal 10 mm floor gap remains a test risk because the datasheet's peak response is at 2.5 mm.

## D-022

**2026-09-30 · Chassis / fastener sourcing and J12/J13 stacks · CANDIDATES; supplier confirmation and fit qualification open**

**Decision:** when OnlyScrews did not show a suitable exact item, record the best next-source candidate or a supplier quote request in the canonical BOM. Do not represent a family listing or a near size as confirmed stock or a drop-in part.

**Joint stack candidates:** J12 / CH-038 uses an M3 × 12 hex-socket countersunk screw candidate, based on the modeled 4 mm deck and 8 mm tapped engagement. J13 / CH-035–037 uses M4 × 12 button-head bolts, accessible plain M4 hex nuts and the existing Ø4 × 8 dowel candidate. The modeled J13 stack is 11.2 mm, leaving 0.8 mm nominal bolt projection without washers. The BOM and [joint register](01-chassis/v1/joint-register.md) now record these choices and the needed seat, engagement, clearance, access and fit checks.

**Other source decisions:** seek DIN 7984 low-head screws from Royal Fasteners; use the Desertcart M3 × 5.7 × 4.6 insert variant only if the exact option is confirmed and coupons pass; use JCPlas B4B66/B4B67 plastic thread-formers as quote/sample candidates for M2 joints; use UAVstore's M3 × 18 button screw option as a sample candidate; and ask Royal Fasteners whether it can supply the still-unconfirmed M3 × 2.5 DIN 916 cup-point set screw. Industrybuying's Loctite 641 is the source candidate for bearing retention, separate from Loctite 222 threadlocker. Probots is the primary candidate for exact 2.5 × 100 mm cable ties, with RoboComp as a backup. CH-061 remains an OnlyScrews candidate with a marginal 0.05 mm nominal radial interference in its current pilot and requires a coupon.

**Status and limits:** source pages and stock were reviewed on 2026-09-30; availability may change. No suppliers were contacted and no fasteners ordered or received. CH-030/060 exact stock and head dimensions, CH-055's 2.5 mm availability, plastic-screw geometry/pilot, and all physical fit/proof checks remain open. No CAD geometry changed under this decision.

## D-023

**2026-09-30 · Chassis / fastener availability update · CH-035 and CH-038 reported available; CH-030/055/060 unsourced**

**Builder-reported availability:** CH-035, M4 × 12 mm hex-socket button-head SS304, is available from OnlyScrews. CH-038, M3 × 12 mm Phillips CSK mild-steel black-oxide, is available. The CH-038 product URL was not supplied, and the previously inspected OnlyScrews page showed a different SS304 item with conflicting stock text; confirm the received part's identity and countersink fit. Neither report records an order or receipt.

**Open sourcing:** the builder could not find a buyable match from the Royal Fasteners leads. CH-030 DIN 7984 M3 × 6 low head, CH-060 DIN 7984 M3 × 8 low head, and CH-055 DIN 916 M3 × 2.5 cup-point remain unsourced. No near-size substitute is approved.

**Image kit:** the pictured assortment contains M5 screws, M5 washers and M5 nuts. It does not match the chassis fastener sizes and is not needed for the listed M3/M4 joints; do not buy it for this BOM.

**Changed:** updated the BOM availability notes, chassis snapshot and fastener sourcing review. No CAD change. J12/J13 received-part fit checks remain open.

## D-024

**2026-09-30 · Chassis / remaining fastener source leads · OPEN; exact size and availability to confirm**

**New leads:** for CH-030 DIN 7984 M3 × 6 and CH-060 DIN 7984 M3 × 8, request exact standard/length and samples from ACME Fasteners through its [TradeIndia low-head socket screw listing](https://www.tradeindia.com/products/low-head-socket-cap-screw-din-7984-or-din-6912-5649111.html). The page is marked in stock and says samples are available, but it does not show the exact M3 lengths or clarify whether its inventory is DIN 7984 versus DIN 6912. Confirm dimensions and standard before treating it as a match.

For CH-055 DIN 916 / ISO 4029 M3 × 2.5 cup-point, [Dalloyed Fasteners](https://www.dalloyedfasteners.com/grub-screw.html) is an Indian manufacturer lead for the ISO 4029/DIN 916 family and M3 grub screws. Its published page does not list a buyable M3 × 2.5 item; ask whether it can supply this short length and provide a sample. The M3 × 3 OnlyScrews item remains an unapproved alternate because it is 0.5 mm longer.

**Changed:** BOM and sourcing review now record the new supplier leads. No supplier was contacted and no purchase or physical fit is recorded. The three exact fastener rows remain open pending source confirmation and received-part fit.

## D-025

**2026-09-30 · Chassis / mixed Phillips-CSK fastener assortment · CANDIDATE; source and fit unverified**

**Correction:** the later assortment image contains M3, M4 and M5 Phillips countersunk screws, plus matching M3/M4/M5 nuts and washers; it is not an M5-only kit. The M3 × 12 compartment is a possible source for CH-038, pending seller confirmation of material/grade and measured countersink dimensions. The M4 × 12 compartment is countersunk and does not replace the selected M4 × 12 button-head candidate for CH-035. The earlier separate image was an M5 button-head assortment and does not match the chassis fastener sizes.

**Changed:** clarified the chassis BOM and fastener sourcing review. No kit link, purchase, receipt or fit check is recorded.

## D-026

**2026-09-30 · Chassis / battery and ballast CAD (CH-022, CH-038, J12) · ACTIVE; PCB-01 height and received-part fit open**

**Why:** an audit found the CAD out of step with the BOM. The two 25R cells were 0.2 mm apart, but the BOM notes Samsung asks for more than 1 mm. CH-038 is a countersunk screw, but the CAD modeled a cylinder head in a flat counterbore. The TCRT mass note said ~300 mm, but CH-020 specifies a 350 mm lead. `chassis-v1.step` also predated the latest source edits.

**Changed in `01-chassis/v1/cad/body_chassis_model.py`:**
- **Cells:** `BATTERY_CELL_PITCH` went from 18.6 to 19.5 mm, giving a 1.1 mm gap at the 18.4 mm maximum cell diameter. The pack envelope grows to 38.5 × 67.0 × 23.5 mm. The tub front wall stays at X 67, so the rear wall moves 0.9 mm back to X 24.0 and the pack centre to X 46.25. The hatch, deck opening and shell floor opening follow from the same constants.
- **CH-038 / J12:** the ISO 7046-1 M3 × 12 head is modeled as a 90° cone to the Ø5.5 rim with k 1.65. It sits in a 90° deck countersink, Ø6.5 at the deck top, 0.1 mm below flush. The bar's tapped holes deepen from 8 to 9 mm, giving 8.1 mm engagement with 0.9 mm tip clearance; before, the tip reached the hole floor. The screw mass now comes from the modeled head.
- **TCRT mass note** now says 350 mm (CH-020). The mass is unchanged.

**Mass register:** the ballast row went from 81.6 to 81.1 g (lighter CSK heads, deeper holes). The battery row centroid moves −0.45 mm in X. Total mass went from 2605.5 to 2605.0 g and CoM X from +19.05 to +19.03 mm (h 105.87 mm). a_tip is 1.763 m/s², against a 1.582 minimum. Measured printed-volume changes (hatch +126, tub walls +52, front deck −134, shell −162 mm³) come to less than 0.2 g, so those rows were not edited.

**Checks:** the new `cad/check_battery_ballast.py` (about 10 min) passes all ten rows and writes `generated/battery-ballast-checks.json`. Those rows cover pack clashes, cell gap, tub margins (1.8 mm front/rear, 1.5 mm side), ballast clashes, head seat, screw length, tip clearance and the CoM margin line. It reports four overlaps as OPEN. They are identical, or differ only by the lengthened hatch, in a copy of the model with this change reversed:
- **Hatch flange × shell floor:** 1689 mm³ (1665 mm³ before). The flange is wider than the shell opening. This is a real, unresolved interface issue that the Sep 27 saved report does not show.
- **Front deck × shell:** 39 mm³.
- **Front deck × power-board proposal envelopes:** 178 mm³.
- **Front deck × IMU screws:** 25 mm³, by design.

The full `check_layout.py` was not rerun. `chassis-v1.step` was rebuilt from the current source. Its product list also reflects earlier source changes: the DRV8833 and GP2Y0A21 envelopes and the Ø3 × 1.5 magnet.

**Changed docs:** the chassis BOM battery note, the CH-022 and CH-038 rows in `BOM.csv`, joint-register J12 and the CAD README.

**Open:** the PCB-01 height is still a 2.9 mm placeholder, pending measurement. The pack build must hold the 1.1 mm cell gap. The received CH-038 head angle and diameter must be checked against the seat. The hatch/shell interface is unresolved. A full `check_layout.py` rerun is needed before release.

## D-027

**2026-09-30 · Chassis / purchased-part models (CH-017, CH-018; J08A, J08C) · ACTIVE; received-unit fit open**

**Why:** the builder asked why the Adafruit driver was only a box, and for other boxed modules to be found and fixed. Two purchased modules in the chassis v1 export were boxes: the Adafruit #3297 driver and the GP2Y0A21YK0F.

**Sources** (details in [purchased/README.md](01-chassis/v1/cad/purchased/README.md)):
- **step.parts:** has neither part (searched 2026-09-30).
- **Sharp:** a community STEP of the A21 sits byte-identical in two unrelated GitHub repositories. It matches the Sharp datasheet outline (E4-A00201EN) to 0.05 mm.
- **Adafruit:** no STEP exists. `purchased/adafruit_3297_drv8833.py` builds one from Adafruit's own Eagle board file: outline, corner radii, holes and part placements. Package bodies are nominal, and the terminal-block height is estimated.

**What the real sensor showed:** the model had the package wrong, and Layout 02 had it wrong with the A41 STEP too. It read the connector as the lens face, so the A41 in Layout 02 was looking upward.
- The lenses and the Ø3.2 ear holes face the same way.
- The package is 13.5 mm deep along the optical axis, and 18.9 mm tall because the connector sits on one edge.
- The ears span 44.5 mm, but the pod is 35 mm wide.

**Builder decisions (2026-09-30):** trim both ears to the 29.5 mm body and clamp the body between seat and lid. Solder the J10-8 wires to the S3B-PH pins, with no plug.

**Changed in CAD (`body_chassis_model.py`):**
- **Sensor:** the STEP (ears trimmed in the model) sits lenses +X, connector up, face at X 128, on the Z 35 seat. The optical axis moves from Z 40.3 to Z 41.5 (lens 6.5 above the body bottom), and the window follows.
- **Pod:** the nose top rises from Z 49 to Z 51. The lid underside is level at Z 49 all the way to the face, replacing the step down over a "lens hood". The front pocket is ±15.0, up from ±14.0. The lid screw moves to (111.8, −11.8), behind the sensor, from (124.6, −11.8), which was inside the real sensor.
- **Lid hump:** the lid has a hump over the header and a 3 mm soldered-lead reserve, 1.2 mm walls, top at Z 58.6. It runs 11.5 mm rearward so the D-011 11 mm forward slide still works, and it gives the lead a path back and down behind the sensor.
- **Cap:** the cap has a top notch so the hump clears its 3 mm travel. The ear slots stay, now vestigial.
- **Drivers:** the #3297 boards lie flat at Z 66 with their long side along X and the terminal block forward, 10.1 mm tall. They are centred 1.5 mm further back, at X 44.5. The real PCB corner otherwise reaches 0.7 mm into the front body-mount doglegs; the old box overlapped them by about 20 mm³.

**Mass:** the nose row goes from 18.7 to 18.9 g (measured pod/lid/cap volume +0.27 cm³). The driver row moves to X 44.5. The register total is 2605.2 g, with CoM (+19.03, 0.16, 105.86) and a_tip 1.763 m/s² against 1.582.

**Checks:**
- `check_nose_joints.py`: all 12 rows pass.
- Nose clash sweep: pod, lid, sensor, cap at rest and at 3 mm, against the body, frame, electronics and harness. Only the designed insert interference shows, and the optical axis is unobstructed. The sensor has 0.5 mm to the lid and 0.5 mm to the cap at full travel.
- Driver sweep: no clashes, 0.8 mm to the dogleg.
- `check_nose_service.py` subset C: cap, lid, sensor and lid-screw paths are clear.
  - `hall_board_up` now needs the sensor removed first (the sweep was updated); the old order hit the sensor at 3 mm.
  - The subset run overwrote the full report, so I restored the committed full report and merged the rerun rows (§) into it.
- `chassis-v1.step` rebuilt. The full `check_layout.py` was not rerun.

**Changed docs:** `purchased/` with its README, the CH-018 row in `BOM.csv`, the chassis BOM A21 note, joint-register J08A/J08C (J08A still named the A41), the CAD README and `check_layout.py` labels.

**Still boxes:** the PCB-01 protection module has no drawing or model and an unmeasured height. The custom boards (PCB-07, the Hall carrier, the power-board proposals) are the project's own designs.

**Open:** check the received A21 and #3297 against the STEPs; ear-trim quality; soldered-lead strain relief; hump and cap-notch print and dust ingress; bench-check the stop-path timing (unchanged).

## D-028

**2026-10-01 · Chassis / battery tub interfaces (J11A, CN-05) · ACTIVE; boss and insert fit unproven**

**Why:** `check_battery_ballast.py` (D-026) reported four overlaps as OPEN. The builder asked for the hatch, deck and power-envelope overlaps to be fixed, and the IMU one recorded as accepted.

**Root causes:**
- **Hatch × shell (1689 mm³):** the hatch lies inside the shell floor's thickness (Z 30.5–32.0 in a Z 30.0–32.4 floor). The floor opening was the tub plus 1 mm, but the hatch flange is wider, so its screw holes sat in shell material.
- **Front deck × shell (39 mm³):** four 0.4 mm slivers where the tub screw bosses (from Z 32) entered the shell floor outside the opening.
- **Front deck × power envelopes (178 mm³):** the CN-05 fuse-holder and disconnect-pair envelopes share the 11.3 mm channel between the tub's +Y wall and the rail with the +Y bosses. Neither envelope can move sideways. Raising the fuse would hit body-mount nut 4 (Z 48.8).
- **Front deck × IMU (25.133 mm³):** exactly the two M2 shanks, 4 mm into the deck (2·π·1²·4), by design.

**Changed in `01-chassis/v1/cad/body_chassis_model.py`:**
- **Shell opening:** now the hatch outline plus `BATTERY_HATCH_GAP` 0.5 mm, from new `BATTERY_HATCH_X` / `BATTERY_HATCH_HALF_Y` constants shared with the hatch.
- **Bosses:** one constant, `TUB_BOSS_XY`, now used by both the tub and the front deck print. The rear pair stays at (28, ±39.5). The front pair moves from (64, ±39.5) onto the front wall's face at (71.5, ±34.35), midway between the ballast bar (|Y| 30) and the fuse holder (Y 38.7). All four stop at `TUB_BOSS_TOP_Z` 39.5, 1 mm over the unchanged Ø4.3 × 7 insert pilots (was Z 41).
- **Hatch:** grows forward from X 71 to X 75 to carry the front screws, leaving 3.5 mm to the edge (M3 washer radius). Its Y extent is unchanged.
- **Pack interface (CN-05):** the disconnect pair, its tub-wall service window and slide path move from Z 37–47 to Z 40–50, clear of the rear +Y boss. The fuse holder is unchanged.

**Mass register (measured against the committed model):** shell −4.04 cm³, so `BODY_SHELL_AND_PANELS` goes from 290.4 to 285.6 g. Frame +0.29 cm³ at 0.571 g/cm³, so `CHASSIS_PRIMARY_FRAME` goes from 206.8 to 207.0 g. The register total is 2600.6 g, CoM (+19.03, 0.16, 105.88), a_tip 1.763 m/s² against 1.582.

**Checks:**
- `check_battery_ballast.py`: all ten rows pass with no OPEN overlaps. The IMU overlap is in a new ACCEPTED list and passes only at 25.133 mm³. Hatch/shell or deck/shell overlaps now fail instead of being reported.
- Pack-interface sweep (pair, fuse, slide path against the whole model): no clashes. The window still opens through the wall.
- `chassis-v1.step` and `body-chassis.step` rebuilt.
- Full `check_layout.py`: 116 of 119 rows pass, in 14 min. All the tub, hatch, ballast, pack-disconnect and IMU rows pass. The window reads Z 40–50. The three failures are listed under **Found, not changed**.
- **`check_layout.py` repaired so it completes** (first full run since Sep 27). Under the substitute runtime (OCC 7.9.3), whole-compound booleans against the C3/DevKitC compound ran away: the J33/J34 reserve reached 133 GB and macOS killed the run at about 37 min, twice.
  - `_boxes_meet` now also needs a leaf of each compound to meet. That only drops pairs whose overlap must be zero.
  - The C3 carrier's own plug reserves are skipped against the C3 compound before the boolean; their results were already discarded.
  - The IMU deck row picked the first `CHASSIS_DECK_WITH_BODY_INTERFACE`, which since the frame split is the rear print. It now picks the print the IMU screws are in, and reads 12.566 mm³ per shank.

**Found, not changed** (the three failing `check_layout.py` rows, all outside this change and likely from D-027):
- `connector_reserves_clear_of_real_hardware`: the PCB-03 J31/J32 and J33/J34 edge-connector reserves overlap the #3297 driver boards by 140 mm³ each.
- `connector_bodies_clear_of_hardware_and_each_other`: the J3_1 and J3_4 mated Micro-Fit plugs overlap the driver boards by 82 and 89 mm³.
- `front_panel_lifts_off_forward`: the front panel's removal path hits `BALL_POD` by 171 mm³, which points to the D-027 nose rework (nose top Z 49 to 51).

**Changed docs and scripts:** the CAD README, joint-register J11A, `check_battery_ballast.py`, `check_layout.py`, and the regenerated `generated/checks.md` and `checks.json`.

**Open:** boss print quality with a 1 mm roof over the inserts; front-boss access with the ballast bar fitted; the J11A screw and insert BOM rows (unchanged); the three D-027 `check_layout.py` failures above.
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

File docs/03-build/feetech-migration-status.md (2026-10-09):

# Feetech migration execution status (2026-10-07)

This tracks the user's 0–3 checklist against evidence in `03-build`. The
selected servos are **candidates**, not released production actuators. The
existing head CAD still installs XC330 pitch/roll geometry, while the body CAD
now installs the Feetech ST3215-HS on yaw. Head axes, FEA, electrical hardware
and final whole-robot stability remain provisional until the mechanical and
bench gates below close.

| Checklist | Result | Evidence / remaining gate |
|---|---|---|
| 0.1 / 0.3 source data | Partial | STS3045M drawing-based [reference STEP](03-head/v1/cad/purchased/sts3045m_reference.step) and [official ST3215-HS STEP](02-body/v1/cad/purchased/waveshare_feetech_st3215_hs_servo.step); Feetech protocol and memory table recorded in [screen](03-head/v1/feetech-actuator-screen.md). The HS official STEP has one invalid-topology main-case solid, so it is packaging evidence only. The STS3045M horn, tooth geometry and tolerance data are missing. |
| 0.2 physical inputs | Blocked by unavailable hardware | No STS3045M, HS, USB adapter or 12 V bench supply available; [B1–B6 protocol](03-head/v1/feetech-bench-protocol.md) is ready but cannot be run. |
| 1.1–1.4 actuator math and storyboard | Provisional screen and mass sensitivity complete | [Screen](03-head/v1/feetech-actuator-screen.md) records terminal-voltage torque proxy, reflected head motor inertia, P01–P09, and thermal gate. [Storyboard](03-head/v1/feetech-motion-storyboard.md) revises the fast pitch segments. The [unchanged-structure mass what-if](03-head/v1/cad/generated/feetech-mass-whatif.json) quantifies the two 34.8 g cases. Re-running §11.3 from a redesigned mass tree and P07 FEA requires refitted CAD; these are not numerically closed. |
| 1.5–1.9 power | Architecture calculations complete, schematic open | [Power delta](04-pcbs/power-boards.md#4a-feetech-actuator-rail-delta-d-046d-047-2026-10-07) covers 5.5 V divider, 5.23 V terminal minimum, 5.9 V clamp target, 12 V converter loading/heat, braking, overload/current monitor and duty-dependent runtime. Converter schematic, thermal PCB layout, clamp and measured duty are open. |
| 1.10–1.13 harness/bus | Preliminary specification | [Harness](05-harness/README.md) and [bus contract](04-pcbs/feetech-link-contract.md) record 5264-3P, pinout, supply separation and W42 budget. PCB-12 transceiver VIH/VIL, contention and mixed-rail behavior remain bench B5 and schematic gates. |
| 1.14–1.15 firmware/interface | Build contract authored | [Bus contract](04-pcbs/feetech-link-contract.md) gives packet, IDs, 1 Mbps, homing, ±58° yaw counts, dead zone and fault state. This repo contains no C2 firmware implementation to update. |
| 1.16–1.18 ledger/BOM | Updated | `BOM.csv`, head/body BOMs and `decisions.md` carry candidate hardware, tools, horn/screw procurement holds, BO-056/061 holds and D-044 index repair. |
| 2.1–2.7 / 2.9 head CAD | **Installed in the live head (D-049); received-part fits open** | Step 0 checked the STS3045M STEP against the drawing (axis and slots right; lead exit, slot necks and boss corrected). Roll: goBILDA coupler and ear plate, rear bearing moved forward. Pitch: servo on the pitch frame, horn screwed to the +Y yoke leg. `check_revision.py`, `check_fasteners.py`, `check_integration.py` and the motion envelope pass; A0 re-solved. Open: received horn, coupler and thread fits. |
| 2.8 / 2.10 head FEA / print edge | **FEA done (D-049); CF leg coupon open** | Pitch frame 112.5, +Y leg 49.9, roll 455.9 N·m/rad: pitch chain 31.6 Hz in PLA, 25.6 Hz at 2.3 GPa, 34.3/31.5 Hz with CF legs at 4.5 GPa; roll 126 Hz. Both yoke legs print in CF-filled filament; coupon the modulus. Watertight export check not re-run. |
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

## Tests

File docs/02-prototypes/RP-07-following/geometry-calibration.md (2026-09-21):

# RP-07 geometry and calibration

| Field | Value |
|---|---|
| Status | Procedure complete on paper; all numeric calibration results `U` |

## 1. Required frames

```text
I: image pixels
C: optical camera frame
H: rigid head frame
N: neck/body reference frame
B: base frame
O: local odometry frame
```

Use the project-wide handedness and sign convention. Every transform record names parent/child frames, units, calibration revision and uncertainty.

The observation-time chain is:

```text
pixel → calibrated ray C
      → T_H_C
      → T_N_H(q_roll,q_pitch,q_yaw at capture)
      → T_B_N
      → optional T_O_B(base pose at capture)
```

Full rotation and translation are required. Rotation-only treatment is inadmissible at close range.

## 2. Calibration artefacts

| ID | Artefact | Method | Physical evidence required |
|---|---|---|---|
| `CAL-01` | Intrinsics/distortion for each used mode/crop | Printed target across central/peripheral FOV | Images, target dimensions, reprojection residuals |
| `CAL-02` | Camera-to-head rigid transform | CAD prior plus measured target/fixture solve | Fixture record, transform and covariance |
| `CAL-03` | Head joint zeros/axes and head-to-body transform | RP-01 calibration plus surveyed camera target | Joint logs and external measurement |
| `CAL-04` | Camera↔joint timestamp mapping | Repeated visible/electrical motion event | ≥100 samples, offset, P95 residual, outliers |
| `CAL-05` | Rolling-shutter/readout model | Stationary calibrated target during known head rates | Error versus row/rate/exposure |
| `CAL-06` | Base yaw/odometry alignment | Marked floor heading and controlled turns | Encoder/IMU/external heading comparison |
| `CAL-07` | Range-cue calibration | Marked person/target distances and poses | Error/bias by cue, range and visibility |

Any relevant mechanical, focus, sensor mode, crop, mount, joint-zero, firmware or camera replacement invalidates the affected calibration.

## 3. Effective capture time

Carry `SensorTimestamp`, exposure time and frame duration. The implementation must document whether its effective time refers to start, midpoint or another modeled instant and how rolling-shutter row time affects the chosen anchor.

For observed angular rate `ω`, the inherited alignment condition remains:

```text
|Δt|95 × |ω| ≤ 0.3°
```

When that cannot be met, widen bearing uncertainty or exclude the motion interval from high-accuracy tracking. Do not silently reuse the settled-head uncertainty.

## 4. Bearing

Undistort the selected anchor, form a unit camera ray and transform it with measured head/base pose at effective capture time. The output includes angle and uncertainty. Raw box centre never directly becomes a servo command.

Anchor preference:

1. calibrated eye-region/face landmark anchor;
2. calibrated face-box fallback;
3. stable upper-body/head estimate;
4. person-box control point for follow geometry only.

Transitions use hysteresis so intermittent face evidence does not create gaze jumps.

## 5. Range cues

| ID | Cue | Valid when | Known failure |
|---|---|---|---|
| `RC-01` | Ground-plane ray through foot/lower-body contact | Ground and lower body visible; calibrated pitch/height | Occlusion, crop, non-level floor, wrong foot point |
| `RC-02` | Visible-joint/known-height prior | Required joints visible and target-specific or population prior accepted | Pose error and human-size variation |
| `RC-03` | Selected-person apparent width/scale | Clean selection samples exist; torso/shoulders visible | Pose, clothing, yaw and arm variation |
| `RC-04` | Temporal size/radial trend | Track stable over time | Gives change more reliably than absolute range |
| `RC-05` | Non-safety external range association | Future sensor ray can be associated without ambiguity | Range may hit another object/person |

Use cue availability and quality to fuse a coarse estimate. `range_sigma_m` must grow when cues disagree, visibility degrades, calibration is stale, or the person is near an image edge.

## 6. Control eligibility

| Geometry state | Head attention | Base alignment | Forward come/follow |
|---|---|---|---|
| Fresh bearing, no range | Allowed within uncertainty | Allowed if C3 safe | Forbidden |
| Fresh bearing + valid coarse range | Allowed | Allowed | Eligible within registered uncertainty |
| Prediction inside brief gap | Bounded/slow; uncertainty grows | No new acceleration | No forward motion after freshness boundary |
| Stale pose or calibration | Inhibit | Inhibit | Inhibit |

## 7. Validation outputs

Report bearing and range error by distance, FOV sector, person pose, head pose/rate, base motion, lighting, anchor/cue, and occlusion. Summary percentiles without those strata are insufficient for selection.

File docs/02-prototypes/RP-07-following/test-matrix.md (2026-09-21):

# RP-07 test matrix

| Field | Value |
|---|---|
| Status | Complete test design; all execution/result cells `NOT RUN` |
| Rule | Pilot data may tune methods and estimate variance; scored thresholds freeze before scored trials |

## 1. Controlled factors

Each run selects and records a value from every applicable factor.

| Factor | Required levels/direction |
|---|---|
| Distance | 0.6, 0.9, 1, 2 and 3 m where geometry permits |
| Horizontal sector | Centre, intermediate left/right, useful-FOV edge |
| Vertical geometry | Standing, seated/crouched if in scope, camera/head pitch cases |
| Lighting | Registered bright, ordinary, dim household; backlight case |
| Appearance | Light/dark clothing, pattern, outer layer, skin-tone/face-accessory coverage |
| Pose/view | Front, side, back, walking toward/away/across |
| Head state | Settled; small tracking motion; registered search slew |
| Base state | Stopped; straight; gentle turn; braking |
| People | Target alone; target + distractor; similar-looking distractor |
| Visibility | Full; upper body; partial occlusion; complete temporary occlusion; exit/re-entry |
| System load | Perception only; representative integrated load; peak registered concurrency |

Exact lux, ambient, floor, clothing articles, subjects/test material and repetitions are filled at gate registration.

## 2. Phase A — offline and synthetic, no motion authority

| ID | Case | Required result | Status |
|---|---|---|---|
| `T07-A01` | Coordinate/ray unit vectors | Signs, frames and units match convention | NOT RUN |
| `T07-A02` | Recorded acquisition matrix | Candidate latency/recall/false positives reported by stratum | NOT RUN |
| `T07-A03` | Empty-room/media/mirror sequences | False locks characterized; no safety use | NOT RUN |
| `T07-A04` | Detector backend comparison | Same corpus/config accounting; winner by predeclared rule | NOT RUN |
| `T07-A05` | Multi-person association | Fragmentation and ID switches measured | NOT RUN |
| `T07-A06` | Selected-person lock | Distractor never silently replaces target | NOT RUN |
| `T07-A07` | Occlusion/re-entry | Same-person accept/reject/unknown behavior recorded | NOT RUN |
| `T07-A08` | Stale/frozen/out-of-order frames | Freshness/fault states and zero-goal timing correct | NOT RUN |
| `T07-A09` | Recorded head/base pose replay | Ego-motion compensation and uncertainty checked | NOT RUN |
| `T07-A10` | Range-cue replay | Error/bias/uncertainty coverage by cue and distance | NOT RUN |
| `T07-A11` | Deterministic replay repeat | Outputs within declared reproducibility tolerance | NOT RUN |
| `T07-A12` | IPC fuzz/invalid values | Consumers reject wrong epoch, NaN, stale and invalid geometry | NOT RUN |

## 3. Phase B — live camera, motors inhibited

| ID | Case | Required result | Status |
|---|---|---|---|
| `T07-B01` | Camera modes/focus/exposure | Selected mode and policy documented | NOT RUN |
| `T07-B02` | Intrinsic/extrinsic calibration | Residuals and uncertainty recorded | NOT RUN |
| `T07-B03` | Camera↔joint time alignment | Mean, P95, outliers and angular implication recorded | NOT RUN |
| `T07-B04` | Rolling shutter/head motion fixture | Validated motion envelope or explicit degradation | NOT RUN |
| `T07-B05` | Live acquisition matrix | Inherited acquisition/rate gates measured | NOT RUN |
| `T07-B06` | Live distractor/occlusion | No silent switches; loss/reacquisition trace | NOT RUN |
| `T07-B07` | Representative compute coexistence | Latency/rate/memory/thermal acceptance | NOT RUN |
| `T07-B08` | Camera/process restart | Session invalidation and bounded recovery | NOT RUN |
| `T07-B09` | Privacy/default operation | No unrequested persistent raw frames | NOT RUN |

## 4. Phase C — head only

| ID | Case | Required result | Status |
|---|---|---|---|
| `T07-C01` | Search sectors | Coverage, limits, interruption and timeout correct | NOT RUN |
| `T07-C02` | Acquire/orient | Smooth orient; no raw-box twitch; timing joinable | NOT RUN |
| `T07-C03` | Stationary target tracking | Bearing error/jitter and head settling pass | NOT RUN |
| `T07-C04` | Moving person | Sustained target updates without self-excited oscillation | NOT RUN |
| `T07-C05` | Face loss/body continuity | Anchor hysteresis prevents jumps | NOT RUN |
| `T07-C06` | Large head slew | Predicted/degraded behavior bounded; no false confidence | NOT RUN |
| `T07-C07` | Base-yaw relay fixture/simulation | C2 counter-yaw primitive meets timing or safely degrades | NOT RUN |

## 5. Phase D — guarded minimum-speed base

Prerequisites: applicable RP-03 gates, workbench readiness, Floor mode, physical E-stop, registered ballast/CoM, stopping limits and caught/guarded setup.

| ID | Case | Required result | Status |
|---|---|---|---|
| `T07-D01` | Fresh target alignment only | Base turns inside limits; head counter-yaw coordinated | BLOCKED / NOT RUN |
| `T07-D02` | Observation loss during alignment | Brake/stop within bound; no resume | BLOCKED / NOT RUN |
| `T07-D03` | Low-speed straight approach to marked surrogate | Range/control/stopping pipeline proven before person | BLOCKED / NOT RUN |
| `T07-D04` | Local obstacle conflict | C3 clamp wins and action reports safety stop | BLOCKED / NOT RUN |
| `T07-D05` | Tabletop denial | No ordinary base motion; denial logged | BLOCKED / NOT RUN |

## 6. Phase E — come

| ID | Case | Required result | Status |
|---|---|---|---|
| `T07-E01` | 1 m frontal come | Settle 0.6–0.9 m without contact/creep | BLOCKED / NOT RUN |
| `T07-E02` | 2 m frontal come | Same plus speed/stopping margin | BLOCKED / NOT RUN |
| `T07-E03` | Off-axis come | Align/arc policy remains stable | BLOCKED / NOT RUN |
| `T07-E04` | Target moves slightly during approach | Bounded response; no overshoot/contact | BLOCKED / NOT RUN |
| `T07-E05` | Target lost during approach | Immediate bounded brake then stationary reacquisition/failure | BLOCKED / NOT RUN |
| `T07-E06` | Obstacle introduced | C3 intervention; no automatic resume | BLOCKED / NOT RUN |

## 7. Phase F — follow

| ID | Case | Required result | Status |
|---|---|---|---|
| `T07-F01` | Straight ≤3 m route | Distance/speed/stability within registered bands | BLOCKED / NOT RUN |
| `T07-F02` | Gentle turn | Head/base handoff and distance stable | BLOCKED / NOT RUN |
| `T07-F03` | Temporary partial occlusion | Continuity without switch; motion eligibility obeyed | BLOCKED / NOT RUN |
| `T07-F04` | Complete brief occlusion | Brake first; stationary same-person reacquisition only | BLOCKED / NOT RUN |
| `T07-F05` | Target exit/re-entry | Stop; accept same target or fail honestly | BLOCKED / NOT RUN |
| `T07-F06` | Distractor crossing | Zero silent switches | BLOCKED / NOT RUN |
| `T07-F07` | Target stops/approaches robot | Smooth stop; no reverse/oscillation/contact | BLOCKED / NOT RUN |
| `T07-F08` | Obstacle/furniture conflict | Local safety wins; action terminal semantics correct | BLOCKED / NOT RUN |

## 8. Phase G — injected system faults

Execute `F07-01…20` first without motion, then only the safe relevant subset on the guarded physical rig. Each run records fault onset, first affected observation/goal, C3 reaction, measured motion, terminal state and whether a fresh action was required afterward.

## 9. Recording and instrumentation

- camera requests and metadata;
- detections/tracks/appearance decisions and selected UUID;
- calibration and configuration/model hashes;
- head commands/measured joints;
- base goals, C3 clamp/fault and measured odometry;
- CPU, memory, temperatures, clocks, fan, power where instrumented;
- external fixed video with visible timing cue and route marks;
- run manifest, deviations and operator annotations.

Human-subject recordings require explicit engineering-recording mode, local storage policy and deletion/retention record.

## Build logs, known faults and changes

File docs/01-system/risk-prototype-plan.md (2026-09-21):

# Makad V1 Risk-Prototype Plan

| Field | Value |
|---|---|
| Status | Approved |
| Version | 1.15 |
| Owner | Project builder |
| Created | 2026-08-14 |
| Last reviewed | 2026-09-21 |
| Depends on | Approved `docs/00-foundation/constraints.md` v1.2, other foundation documents, `system-design-brief.md` v1.2, and `dimensional-baseline.md` v1.12 |
| Decision authority | Project builder |

The prototypes are decision instruments, not partial versions of the final droid. They may use open frames, ballast, external measurement equipment, temporary controllers, and bench power where those choices produce better evidence. A polished appearance is not a pass condition. The approved bench setup and powered-test readiness gate live in `workbench.md`; powered scored testing remains blocked until that gate is satisfied for the active rig and test.

## Roadmap

| Stage | Work | Exit condition |
|---:|---|---|
| 0 | Review and establish the workbench/test-readiness setup + sourcing survey + mass/envelope ledger | Approved readiness gate satisfied, required tools available, stop/isolation verified, and first candidate matrix and cost range exist |
| 1 | RP-06 phase A (sourced envelopes) feeding RP-01 head prototype | RP01 gates pass → provisional ADR-02/ADR-03 |
| 2 | RP-02 electrical/control backbone | RP02-G01/G04/G05/G06 pass and the G02 coexistence invariant is verified on the loads that exist → provisional ADR-03, ADR-12 and the architecture half of ADR-06; `power-energy-ledger.md` populated; ADR-06 sizing bounded, not closed |
| 3 | RP-03 drive and motion safety | RP03 gates pass → provisional ADR-04/ADR-07 |
| 4 | RP-04 coordination, then RP-05 interaction (may overlap) | RP04/RP05 gates pass → provisional ADR-05/ADR-10/ADR-11 |
| 5 | RP-06 final closure + RP-07 following | RP06/RP07 gates pass → provisional ADR-01/ADR-08/ADR-09; spatial-hearing ADR-13 decision |

## Prototype sequence and evidence flow

```mermaid
flowchart LR
    P0["Workbench + continuous sourcing/mass-ledger workstream"]
    P1["RP-01 Three-axis head"]
    P2["RP-02 Electrical and control backbone"]
    P3["RP-03 Drive and local motion safety"]
    P4["RP-04 Coordinated head-body-wheel motion"]
    P5["RP-05 Wake and interaction latency"]
    P6["RP-06 Sourced head/layout mock-up"]
    P7["RP-07 Person tracking and following"]

    P0 --> P1 --> P2 --> P3 --> P4 --> P5 --> P7
    P0 --> P6
    P6 --> P1
    P6 --> P2
```

RP-06 is numbered sixth to preserve the approved portfolio, but its sourcing and envelope work begins with the sourcing workstream and runs alongside RP-01. Its final integrated layout gate closes after representative head, electrical, and acoustic evidence exists.

## Gate and evidence policy

### Gate outcomes

| Outcome | Meaning | Next action |
|---|---|---|
| Pass | All safety, evidence, and decision criteria pass under the registered test conditions. | Adopt the supported decision provisionally and update affected budgets/ADRs. |
| Iterate | The evidence identifies a bounded correction. | Record the failed run, change one named variable set, and repeat. |
| Reject | A candidate cannot meet a Core need or creates unacceptable integration risk. | Remove that candidate and test the next viable option. |
| Defer | Evidence is insufficient for an optional capability and Core does not depend on it. | Remove it from the V1 execution path. This outcome is not available for any Core outcome (e.g. roll/pitch/yaw, come/follow). |

Repeated iteration on the same gate requires a review of the schedule effect and evidence that the remaining problem is localized; iteration without that review is not a valid outcome.

### Threshold registration

Already approved limits cannot be weakened by this plan: the final representative runtime is at least 20 minutes; following is no faster than 0.5 m/s; the initial route is at most approximately 3 m in one household room; come begins at approximately 1–2 m and stops approximately 0.6–0.9 m from the person; tabletop operation is stationary by default.

Where the foundation contains an `SC-TBD-*` or `CON-TBD-*`, the prototype owner must complete a gate-registration record before the first scored run:

| Required field | Content |
|---|---|
| Gate ID | Stable ID such as `RP01-G04` |
| Metric | Quantity, unit, computation, and direction of improvement |
| Threshold | Pass value or allowed range |
| Rationale | Scenario, hazard, storyboard, calculation, datasheet limit, or pilot evidence that produced it |
| Conditions | Load, geometry, supply, floor, lighting, distance, software version, and other controlled conditions |
| Repetitions | Trial count and aggregation method |
| Instrument | Sensor/tool, sampling rate, calibration/check method, and uncertainty where relevant |
| Freeze record | Date and project-builder approval before scored data is inspected |

Pilot runs may be used to make fixtures work and estimate variance. They must be labelled `pilot`, excluded from the scored result, and retained. Scored thresholds cannot be relaxed after results are seen; a change creates a new gate version and requires a documented engineering reason plus a fresh test set.

### Minimum evidence packet

Every prototype produces:

1. test-plan snapshot and gate-registration record;
2. candidate/configuration and sourced-part revision;
3. rig diagram, photographs, ballast and geometry record;
4. firmware/software/configuration revision identifiers;
5. instrument list and calibration/check record;
6. raw timestamped data, event log, and unedited video where motion or perceived timing matters;
7. calculated metrics and trial-by-trial results;
8. faults, anomalies, unsafe observations, and deviations;
9. pass/iterate/reject conclusion;
10. resulting ADR, budget, requirement-threshold, and follow-up changes.

Prototype results should be stored under a later `docs/02-prototypes/RP-XX/` evidence folder. Large raw data and video may live outside Git, but the record must contain stable paths, hashes, or asset identifiers so the conclusion remains auditable.

## Continuous sourcing and data workstream

The approved `workbench.md` collects candidate tools, hazard notes, stop/isolation guidance, a scored-test readiness gate, and a battery gate. The following engineering deliverables begin before RP-01 and stay live through all seven prototypes:

- **Candidate sourcing matrix** — verified specifications, supplier, availability, lead time, substitutes, quantity, landed cost, replacement risk, required tools, and fabrication dependency. Aggregate rows into the first complete project cost range (CON-TBD-13) before major procurement.
- **Mass/envelope ledger** — head, body, battery, drive, electronics, wiring, fasteners, and margin. Unknowns are ranges, not zero. This ledger is the head-CAD blocker and feeds RP-01/RP-06 directly.
- **Power/energy/thermal ledger** — `power-energy-ledger.md`: per-load-group idle/average/peak, transient character, evidence class, state energy model, the RP02-G02 coexistence invariant with its re-run rule, and trip-wires that force a design review. Created by RP-02; updated by every prototype that energizes anything; the power budget.
- **Monotonic event-time strategy** — `timebase.md`: one master clock reference, timestamp-at-source, serial offset reconciliation and the status-light video cue for commands, observations, feedback, health, and external video synchronization. Validated under RP02-G05; required before the first scored RP-01 run.
- **Configuration and run-ID convention** — `run-record-convention.md` prevents data from different builds being mixed; every scored run carries firmware/software/configuration/rig revision identifiers and an immutable evidence manifest.

## RP-01 — Three-axis head mechanism and motion firmware

### Decision question

Can a manufacturable powered roll/pitch/yaw mechanism carry a representative Makad head while producing safe, repeatable, quiet-enough and characterful motion with acceptable range, reversal, settling, camera behaviour, wiring movement, calibration, and controller failure handling?

### Traceability

- Architecture: ADR-01, ADR-02, ADR-03, ADR-08 and ADR-12.
- Success: SC-03, SC-04, SC-05, SC-15, SC-16 and SC-17.
- Thresholds: SC-TBD-03, SC-TBD-04 and SC-TBD-12.
- Constraints: CON-04 through CON-08, CON-14, CON-17, CON-P01, CON-P02 and CON-P05.

### Inputs and candidates

- Concept A, the elevated body-yaw → pitch → coaxial supported-roll serial gimbal documented in `../02-prototypes/RP-01-head/concepts/`, is the RP-01 path. Concept B was explicitly waived before fabrication; this satisfies the alternative-concept rule through recorded elimination rather than an unfinished comparison.
- Current Layout 03 planning inputs: **104 H × 150 W × 115 D mm**, 60 mm neck allocation, nominal D/E masses **~362/436/509 g roll/pitch/yaw at M008=20 g**, and complete-head sensitivity **~499–524 g for M008=10–35 g**. The **external rigid-body** demand model is complete as of 2026-09-13 (`fullproofmath.md`); actuator-internal inertia and structural adequacy are not. Complete-head `W` mass still waits on M008. The tree contains two 23 g XC330-size housings; C01 matches those housings but remains a comparison candidate only. Layout 03 also retains confirmed screw collisions, stop-margin conflict, trial bearing seats, physical-trim and sign-mapping work. Other actuator families and every affected geometry revision still substitute/recalculate before screening. The former 95 mm band, 250 g mass, generic ~0.001 kg·m² and ~0.2 N·m values are inadmissible.
- Selected C2 control boundary: a dedicated Waveshare ESP32-S3-Zero executes synchronized head trajectories and owns the smart-servo bus, limits, watchdog and command expiry; the display ESP32-S3 renders the face. M008 installed mass remains `U`. Servo family remains unselected; C01 paper screen (proposed 5 V, paper OPEN) is recorded in `actuator-screen-01.md`. Protocol/update rate, feedback strategy, homing/calibration method and SKU freeze remain open.
- Preliminary motion storyboard listing the attention, wake, bob, tilt, reversal, tracking-correction, settle, and safe-rest moves the mechanism must support.

### Rig and instrumentation

Use a rigid guarded bench fixture with adjustable ballast at the representative head centre of mass. Record commanded and measured joint state on a monotonic clock. Provide independent video with a visible timing cue and a safe physical stop. Measure or derive joint angle, current, supply voltage, temperature, sound level at a fixed position, structural deflection, and camera image movement. Record cable behaviour throughout the usable workspace.

### Procedure

1. Check static support, fasteners, stops, clearances, cable path, and unpowered movement.
2. Characterize each axis separately at low energy through its proposed range and both directions; for near-CoM candidates, compare the preregistered axis/ballast points without changing fixture stiffness.
3. At fixed commands, measure complete-output load–position hysteresis under a registered bidirectional load sweep and hunting/current during representative hold dwells; then run a distinct impact/tap modal test on the same fixture rather than treating reversal behaviour and resonance as one measurement.
4. Run step, ramp, smooth trajectory, tracking-correction, and settle profiles with representative ballast.
5. Exercise coordinated two- and three-axis wake/attention trajectories, including reversals and interruptions.
6. Repeat tests at relevant head orientations so gravity, cross-axis loading and cable restoring torque vary.
7. Inject command timeout, controller restart, feedback loss, and high-level link loss without defeating the physical stop.
8. Run a preregistered busy-minute RMS/current/thermal sequence before actuator freeze, then a repeated-motion/endurance block and remeasure loaded hysteresis/hold hunting, fastener state, temperature, cable condition, and calibration drift.

### Measurements

- usable roll/pitch/yaw range and forbidden/collision region;
- external static/dynamic torque estimate, actuator-internal acceleration current/torque bound, total torque/current at the simultaneous required speed, and busy-minute RMS current by trajectory; keep transient and continuous/thermal screens separate;
- command-to-motion latency and control update timing;
- absolute/tracking error, repeatability, small-motion resolution, complete-output loaded hysteresis, reversal delay, hold hunting/current, overshoot, settling time, and cross-axis coupling;
- structural deflection, vibration, acoustic level/character, and camera image disturbance;
- temperature rise, calibration drift, angle-dependent cable restoring torque, cable twist/flex, connector movement, and fastener retention;
- stationary RP-01 uses servo encoders for joint angle; a bench IMU may measure backlash/resonance but is not installed head hardware. When locomotion is in scope, record a base-frame IMU separately from commanded neck motion;
- stop, timeout, limit, feedback-loss, and restart behaviour.

### Pass gates

- **RP01-G01 Safety:** every injected stop, timeout, invalid command, feedback-loss, or restart case reaches the registered bounded state without uncontrolled continuation, hard-stop impact, cable damage, or fixture instability.
- **RP01-G02 Three-axis Core:** powered roll, pitch, and yaw each execute their registered authored-motion cases under representative load; no axis is treated as cosmetic or manually positioned.
- **RP01-G03 Motion quality:** registered range, tracking, repeatability, reversal, overshoot, settling, noise, vibration, and cross-axis metrics pass across the scored pose/trajectory matrix.
- **RP01-G04 Integration:** the camera remains calibratable and usable over the registered motion set; wiring clears the workspace and survives the endurance block; the head can reach a safe unpowered or inhibited state.
- **RP01-G05 Buildability:** at least one concept has a credible fabrication, assembly, calibration, service, sourcing, and replacement path with a complete cost range.
- **RP01-G06 Evidence:** commands, measured state, current/voltage, faults and video can be correlated for every scored run.

### Exit decision

Select the provisional head concept and controller requirements for ADR-02/ADR-03, or reject all candidates and repeat RP-01 with a revised concept. A failed Core three-axis gate cannot be converted into a two-axis fallback without reopening approved V1 scope.

## RP-02 — Electrical/control backbone and integrated peak-power rig

### Design question and gate question

RP-02 carries two questions and keeps them separate (v1.10). The design question is the deliverable; the gate question is the falsifier.

**Design question:** what compute/controller split, internal link, rail and protection topology, and energy source lets Makad run representative head, drive, display, camera, audio and compute loads concurrently — and what is the measured margin of that design against each registered state?

**Gate question:** does that design sustain every registered concurrent state and the registered mixed-duty cycle for at least 20 minutes without unsafe motion, unintended reset, rail excursion outside component limits, data staleness or thermal violation — and does every injected fault produce a bounded state?

Evidence documents live in `../02-prototypes/RP-02-electrical/`; the canonical power/energy/thermal budget is `power-energy-ledger.md`; the timebase strategy is `timebase.md`.

### Traceability

- Architecture: ADR-01, ADR-03, ADR-06, ADR-10, ADR-11 and ADR-12.
- Success: SC-14, SC-15, SC-16 and SC-18.
- Thresholds: SC-TBD-10, SC-TBD-11, SC-TBD-12 and SC-TBD-14.
- Constraints: CON-03, CON-07, CON-10, CON-11, CON-P02, CON-P04 and CON-P05.

### Scope note

Battery validation may be staged after bench-supply characterization, but the runtime gate remains open until representative onboard energy hardware is tested safely.

### Rig and procedure

Build a fused/current-limited distribution rig with separately observable load groups for compute, controllers, three head axes, drive, display/light, camera/sensors, microphone and speaker. Use real loads where available and characterized electronic/dynamic substitutes only where their equivalence is recorded.

Test cold start, idle, wake/head movement, base acceleration/reversal, audio peaks, display/camera/perception load, representative maximum safe concurrency, low-energy operation, orderly shutdown, and the mixed-duty scenario. Inject high-level process loss, internal-link loss/corruption or staleness, controller restart, sensor absence, network loss, and one allowed subsystem brownout at a time. Do not deliberately short or abuse an unprotected battery.

### Measurements

- rail voltage/current and transient minimum/maximum by state;
- source current, energy, conversion loss, regulator/driver/wire/connector temperature;
- compute and controller restart, throttling, missed deadline, queue depth and link-error events;
- stop latency and watchdog/inhibit behaviour independent of high-level compute and network;
- idle, representative average, concurrent peak, reserve, low-energy and 20-minute mixed-duty results;
- startup order, shutdown order, stale-command rejection, reconnection and obsolete-work behaviour.

### Pass gates

- **RP02-G01 Protection:** the rig has reviewed isolation, fusing/current limiting, conductor/connector sizing assumptions, and no exposed unbounded hazardous energy path.
- **RP02-G02 Peak coexistence (standing invariant, v1.10):** *every registered concurrent state completes without unintended reset, unsafe motion, rail excursion outside registered component limits, data corruption, or thermal-limit violation.* The invariant and its re-run rule are owned by `power-energy-ledger.md` §5 because it must be re-verified whenever a load group changes evidence class, a load is added, or the servo rail changes; RP-02 registers the rehearsal metric (per-rail minimum expressed as margin, zero resets, CRC and thermal terms) and records which states were verified with which loads and which remain pending.
- **RP02-G03 Runtime (rehearsal with margin, v1.10):** the representative onboard energy configuration completes the registered mixed-duty cycle `MD-01` on the RP-02 rig with recorded energy margin against the 20-minute floor and the SC-TBD-10 reserve and low-energy behaviour. Closure of the 20-minute requirement itself is SC-14 on the integrated droid; a negative or thin rehearsal is an `iterate` on the design now, never a threshold change.
- **RP02-G04 Fault containment:** loss/restart/staleness tests inhibit affected hazardous outputs, reject obsolete commands, expose health state, and recover only from current authorized intent.
- **RP02-G05 Control feasibility:** measured loop/link/timestamp performance supports the RP-01 and projected base-control needs with registered margin.
- **RP02-G06 Serviceability:** isolation, charging connection, battery removal, measurement points, and high-risk module access have credible physical paths.

### Exit decision

Close the first version of ADR-03 and ADR-12 and the **architecture** half of ADR-06 (rail topology, protection, chemistry, isolation, low-energy policy hooks) from cited evidence; record ADR-06 **sizing** (pack capacity, 20-minute closure) as bounded and waiting on the ledger's `W` rows from RP-03/RP-05 loads. Update the power/energy/thermal ledger, and the compute-coexistence and internal-communication budgets, with measured envelopes and margins.

## RP-03 — Drive and local motion-safety rig

### Decision question

Can a candidate wheeled base with representative total mass move expressively at low speed, reverse, turn, spin and stop stably while local obstacle/edge sensing and controller limits prevent harmful or uncontrolled motion in the approved floor and tabletop permissions?

### Traceability

- Architecture: ADR-01, ADR-04, ADR-06 and ADR-07.
- Success: SC-11, SC-12, SC-13, SC-15, SC-16 and SC-25.
- Thresholds: SC-TBD-07, SC-TBD-08, SC-TBD-09 and CON-TBD-14.
- Constraints: CON-09, CON-14, CON-19, CON-P02 and CON-P05.

### Rig and procedure

Use a low open chassis with adjustable ballast matching the current mass range and the baseline `x_CoM=+25 mm`, `h_CoM=124 mm`. Represent the 110 mm **front-support** contact (ball transfer per `dimensional-baseline.md` v1.12) and the rear skid at ~70 mm behind the axle and ≤14 mm above the floor. Keep a swivel-caster comparison article on the same mount. Test on named representative indoor surfaces inside a marked test area. Tabletop edge trials require a physical catch platform or tether that prevents an actual fall without masking sensor/controller behaviour.

Characterize wheel/support geometry, traction, odometry/control feedback, minimum controllable motion, straight travel, reversal, turns, excited-spin candidates, stopping and settling. Repeat at mass/centre-of-mass extremes. Test representative person/furniture/box/cable-like obstacles at each registered approach speed. Verify floor/tabletop permission selection, default inhibition, sensor loss and controller/high-level timeout.

### Measurements

- minimum repeatable speed, speed error, straight-line drift, turn/spin geometry and reversal response;
- stopping time/distance, overshoot/rollback, slip, support chatter, vibration and acoustic noise;
- body pitch/roll or lift indication, wheel/support load behaviour, measured front-support-lift acceleration, skid-contact angle/acceleration, and stability margin versus the preliminary `a_tip≈2.0 m/s²` model;
- obstacle/edge detection coverage, latency, stopping clearance, blind region and false inhibit rate;
- current/energy/temperature by maneuver;
- mode-selection, inhibit, timeout, sensor-loss, restart and hard-stop behaviour.

### Pass gates

- **RP03-G01 Floor control:** the registered forward, reverse, turn, stop and settle maneuvers pass across the floor/load matrix without uncontrolled motion or instability; commanded forward acceleration remains below the registered front-support-lift threshold with margin.
- **RP03-G02 Speed boundary:** the base can regulate the approved slow envelope and cannot exceed the registered test limit; follow trials remain at or below 0.5 m/s.
- **RP03-G03 Obstacle safety:** every scored representative obstacle case meets its preregistered detection/stopping/contact policy with no harmful contact.
- **RP03-G04 Tabletop safety:** ordinary autonomous locomotion, come/follow and excited spin are inhibited by default in tabletop mode; every permitted low-speed edge trial stops within the registered footprint and no trial leaves the caught surface.
- **RP03-G05 Fault containment:** stale commands, lost sensors, lost links, controller restart and hard stop produce the registered bounded state without automatic stale-motion resumption.
- **RP03-G06 Expressive feasibility:** at least one stable turn/spin/reversal profile has sufficiently smooth onset and settling to proceed to coordination testing.

### Exit decision

Provisionally select drive/support geometry and local sensing arrangement for ADR-04 and ADR-07, or reject the candidate. Update mass, motion, stopping, stability, power, acoustic and tabletop-footprint budgets.

## RP-04 — Head–body–wheel coordinated-motion rig

### Decision question

Can measured head and base controllers be composed, synchronized, interrupted, counter-moved and settled as one readable performance rather than as independent actuator commands?

### Traceability

- Architecture: ADR-03, ADR-05 and ADR-12.
- Success: SC-01 through SC-05, SC-09, SC-10 and SC-25.
- Thresholds: SC-TBD-01, SC-TBD-02 and SC-TBD-04.

### Inputs and procedure

Use the measured RP-01 head and RP-03 base models/controllers. Define at least three short semantic performances: wake/attend, acknowledge or curious reaction, and excited turn/spin/settle. For each, create an intentionally independent-channel baseline and one or more composed variants using explicit onset, anticipation, follow-through, counter-motion, interruption and settle rules.

Run each performance from registered start poses, at representative loads and in both uninterrupted and cancelled/interrupted cases. Include controller delay variation and denial/inhibition of one eligible channel. Record semantic intent, scheduled cues, controller commands, measured onset/state, completion/failure and synchronized external video.

### Measurements

- intended versus actual onset and phase offset by channel;
- trajectory tracking, completion alignment, interruption latency and settle duration;
- command freshness, schedule jitter and controller feedback age;
- final pose/velocity and absence of residual unwanted movement;
- blinded observer judgement of attention direction, coherence, intention and preference over the independent baseline;
- degraded performance when one expressive channel is unavailable or base motion is inhibited.

### Pass gates

- **RP04-G01 Timing:** registered onset, phase, interruption and settle metrics pass for all three scored performances.
- **RP04-G02 Bounded interruption:** stop, new higher-priority intent, mode inhibition and controller denial cancel or reshape the performance without stale cues or unsafe continuation.
- **RP04-G03 Coherence:** the preregistered observer protocol rates each composed performance as readable and coherent and demonstrates the required improvement over the independent-channel baseline.
- **RP04-G04 Degradation:** loss/inhibition of one channel produces an honest bounded variant rather than a false-success state or blocked whole system.
- **RP04-G05 Reproducibility:** each performance passes the registered consecutive-run requirement from documented startup/configuration.

### Exit decision

Select the provisional expression/motion composition and scheduling model for ADR-05, and record measured timing requirements with the coordination work.

## RP-05 — Wake and interaction latency path

### Decision question

Can all approved invocation forms and Core semantic requests travel through representative microphone, network/cloud, behaviour and expression paths with acceptable reliability and perceived timing, explicit ambiguity/cancellation, and bounded service failure?

### Traceability

- Architecture: ADR-10, ADR-11 and ADR-12.
- Success: SC-02, SC-05 through SC-07, SC-18, SC-21 through SC-24.
- Thresholds: SC-TBD-05, SC-TBD-13 through SC-TBD-17 and SC-TBD-19.
- Constraints: CON-11 through CON-13 and CON-P03 through CON-P04.

### Scope note

Detailed vocabulary and face/audio polish remain later implementation work.

### Test matrix and procedure

Create a versioned utterance set covering `M4`, `M4K4`, `Makad`, greeting/social response, time, timer, alarm, Spotify, come, follow, stop/cancel, ambiguous wording and unsupported requests. Use registered speakers, distances within approximately 0.3–2.0 m, normal household lighting/noise cases, head/base mechanism noise, M4 audio playback where relevant, and both healthy and deliberately unavailable/slow external service states.

Timestamp audio availability, invocation detection, transcript/semantic result, behaviour acceptance/rejection, first visible/audible acknowledgement, external request lifecycle, physical onset and completion/failure. Test cancellation during pending and active work, reconnection, late response, duplicate response, authentication loss and network loss.

### Measurements

- wake false reject/false wake and semantic accuracy by phrase/environment;
- audio-to-detection, detection-to-intent, intent-to-acknowledgement, external-call and total visible-response latency distributions;
- ambiguity/clarification correctness, cancellation latency and duplicate/late-result suppression;
- microphone contamination from speaker and mechanisms;
- timeout, authentication, network and provider-failure state transitions;
- alignment of wake sound, eyes, status light and head onset.

### Pass gates

- **RP05-G01 Invocation:** each approved name form passes the preregistered trial count, success rate, false-wake and response-latency gates across the registered acoustic matrix.
- **RP05-G02 Core semantics:** the registered natural-language phrase set meets its accuracy/latency gates without collapsing to a rigid one-phrase command grammar.
- **RP05-G03 Lifecycle:** pending, active, cancelling, completed and failed states are observable; late/duplicate results cannot replay obsolete expression or motion.
- **RP05-G04 Failure:** network, authentication, Spotify and cloud timeout cases produce bounded in-character failure feedback and never bypass local motion safety.
- **RP05-G05 Composition:** the visible wake response satisfies the registered cross-channel onset and coherence gates.

### Exit decision

Select the invocation/language/network lifecycle architecture for ADR-10 and the provisional audio/playback path for ADR-11. Close external-network and interaction-latency budget ranges.

## RP-06 — Sourced head-face-camera-audio layout mock-up

### Decision question

Can actually obtainable components fit a serviceable head/body layout that preserves M4's visual identity, display legibility, camera coverage, status-light behaviour, audio function, head dynamics, cable movement, cooling, fabrication and replacement paths?

### Traceability

- Architecture: ADR-01, ADR-02, ADR-06, ADR-08 and ADR-11.
- Success: SC-03, SC-07, SC-08, SC-14, SC-16, SC-17, SC-21 and SC-23.
- Thresholds: SC-TBD-03, SC-TBD-06, SC-TBD-12, SC-TBD-13, SC-TBD-17 and SC-TBD-19.

### Scope note

Sourcing/envelope updates continue during RP-01 through RP-05. Final closure occurs only after their relevant measured inputs exist. Working CAD lives in `docs/02-prototypes/RP-06-cad/` (head Layout 03 and body/chassis Layout 02).

### Mock-up and procedure

Build an adjustable physical mock-up or envelope rig using sourced dimensions and realistic mass dummies inside `dimensional-baseline.md`. Include the selected no-touch Waveshare ESP32-S3-LCD-4.3 (SKU 30493), its window/mount/connectors, the selected visible-light Raspberry Pi Camera Module 3 Wide (SC0874), its mount/connector/moving interconnect, status light/optics, a representative moving-head load from the current Layout 03 D/E tree (**~499–524 g complete, nominal 509 g at M008=20 g**; the former ~250 g target is inadmissible), head structure/joints and remaining moving cable bends/connectors. In the body, include the four-microphone PDM array, speaker/enclosure, low and forward battery placement, Raspberry Pi 5 2 GB with official Active Cooler, remaining electronics, cooling paths, fasteners and service-removal paths.

Evaluate display/face legibility over registered angles/distances/lighting; camera field of view and occlusion throughout head motion; LED visibility, light leakage and camera interference; speaker output and enclosure vibration; microphone contamination; heat-source spacing; cable motion; assembly order; and removal of named high-risk modules.

### Measurements

- mass, centre of mass, inertia proxy and physical envelope with uncertainty/margin;
- display viewing geometry, brightness/contrast and camera/display optical interaction;
- camera coverage/occlusion/calibration stability over head range;
- status-light visibility and image interference;
- acoustic output, vibration and capture contamination at registered conditions;
- temperature/airflow assumptions and service access time/tool list;
- verified availability, lead time, substitute, landed cost and fabrication/tool needs.

### Pass gates

- **RP06-G01 Physical viability:** at least one layout fits all Core head functions with registered assembly, motion, connector, cooling and service clearances plus explicit design margin.
- **RP06-G02 Perception/display:** face legibility and camera coverage pass the registered environment/geometry matrix throughout the required head workspace.
- **RP06-G03 Optical/acoustic compatibility:** status light and display do not unacceptably corrupt camera evidence; speaker/mechanism output and microphone capture meet the registered prototype bars.
- **RP06-G04 Dynamic compatibility:** measured/estimated mass and centre of mass remain inside the RP-01 validated envelope, or RP-01 is rerun with the revised load.
- **RP06-G05 Sourcing:** each architecture-critical component has a verified source, complete landed cost and at least one acceptable substitute or an explicitly accepted single-source risk.
- **RP06-G06 Serviceability:** the named high-risk module replacement can be demonstrated without destructive disassembly or removal of unrelated structural assemblies.

### Exit decision

Select the provisional head sensory/audio layout and sourcing strategy around the already locked display for ADR-01, ADR-08 and ADR-11. Keep binding envelopes and margins in the working CAD and the dimensional baseline. Reopen the display selection only through the recorded hard-failure change-control rule in `display-candidate-study.md`.

## RP-07 — Person tracking and short household following loop

### Decision question

Can Makad acquire, select, retain, lose, reacquire, approach and follow one person within the approved household envelope while respecting observation freshness, camera/head motion, stopping distance, obstacles, mode permissions and local safety?

### Traceability

- Architecture: ADR-03, ADR-05, ADR-07, ADR-09 and ADR-12.
- Success: SC-08, SC-11, SC-12, SC-15 and SC-24.
- Thresholds: SC-TBD-06, SC-TBD-07, SC-TBD-08 and SC-TBD-18.
- Constraints: CON-09, CON-12, CON-19, CON-P02 and CON-P04.

### Route and cases

Mark a level indoor route no longer than approximately 3 m with one gentle turn. Test come from approximately 1–2 m and the approved 0.6–0.9 m stop band. Following speed must not exceed 0.5 m/s. Register household lighting cases, person poses/clothing, approach angles, representative box/furniture/person obstacles, temporary occlusion, target exit/re-entry, distractor person, stale/frozen detections, camera/head movement, sensor loss, controller-link loss and tabletop-mode denial.

Direct spatial-audio localization is not required. Initial search may begin from invocation followed by a bounded visual search.

### Procedure and measurements

Timestamp camera frames, detections, selected-track state, confidence/validity, head pose, target geometry, behaviour intent, base command, local-safety clamp, measured motion and final outcome. Measure acquisition/reacquisition time, track continuity, identity switches, observation/control age, distance/bearing error, approach/follow distance, route completion, speed, stopping, obstacle response and loss-to-stop behaviour.

Run cases in increasing authority: perception replay with no motion; head-only attention; base on guarded floor at minimum speed; come; follow; loss/reacquisition; obstacle and distractor; fault injection. Tabletop denial is tested without authorizing come/follow.

### Pass gates

- **RP07-G01 Acquisition:** the selected approach passes the preregistered acquisition, geometry, lighting and pose matrix within its time/reliability gates.
- **RP07-G02 Continuity:** temporary loss and reacquisition meet the registered policy; M4 never silently switches to a distractor person.
- **RP07-G03 Come:** scored trials begin within approximately 1–2 m, approach without harmful contact, and settle within the approved 0.6–0.9 m band at the registered pass rate.
- **RP07-G04 Follow:** scored trials complete the route at no more than 0.5 m/s while meeting registered distance, continuity, obstacle and stability gates.
- **RP07-G05 Stale/fault safety:** stale, frozen, unavailable or implausible target evidence and lost required sensing/communication cause bounded stop/search/failure behaviour rather than blind continuation.
- **RP07-G06 Permissions:** tabletop mode denies come/follow; local obstacle/edge/stop authority overrides the following controller in every scored conflict case.
- **RP07-G07 Evidence:** perception, semantic intent, control, safety intervention, measured motion and video share enough timing information to explain every success and failure.

### Exit decision

Select the person acquisition/tracking/following approach and compute placement for ADR-09. Close perception freshness, search, loss/reacquisition, distance-control and end-to-end timing budgets for the initial household envelope.

## Spatial-hearing Candidate gate

Spatial hearing remains outside the seven Core risk prototypes. It may receive a separately approved, removal-safe effort only after RP-01 through RP-04 establish a credible mechanical/control path and the Core wake/visual-search/following design does not depend on acoustic direction.

The experiment must compare the approved visual-search baseline against the directional-audio variant on a named Core interaction. Inclusion requires a material, preregistered improvement large enough to justify microphone geometry, synchronized capture, compute, acoustic contamination, cost, packaging and schedule. Otherwise ADR-13 closes with spatial hearing deferred from V1.

## Schedule and concurrency rules

| Work | Earliest start | Dependency/parallelism rule |
|---|---|---|
| Workbench and sourcing | Immediately | Continuous; powered scored work is blocked until the approved `workbench.md` readiness gate is satisfied. |
| RP-06 phase A layout/sourcing | With RP-01 planning | Supplies representative head mass/envelopes; it is not postponed until sixth in calendar time. |
| RP-01 head | After the workbench scored-test gate | First powered mechanical/control prototype. |
| RP-02 electrical/control | Phase A (state register, ledger seeding, power architecture, link contract, timebase, C2 bench-twin timing) immediately; Phase B after a named RP-01 servo load exists (C01 as reference unit, or a later selected family) and the selected Raspberry Pi 5 2 GB is available; Phase C after the `workbench.md` battery gate | Phase A is paper and on-hand hardware and unblocks RP-01's scored runs. G02 rehearsals need representative loads; composite peaks above the bench PSU's 5 A need the candidate pack. PA-04 collapses only on family freeze, not on a C01 purchase. May use bench power before battery validation. |
| RP-03 drive/safety | After bounded controller/power path exists | Uses representative total-mass range; must not share an unvalidated power rig with simultaneous head tests. |
| RP-04 coordination | After RP-01 and RP-03 controllers pass their safety gates | Uses measured response rather than idealized actuator timing. |
| RP-05 interaction | After the observable lifecycle/timebase exists | May overlap late RP-04 work if it cannot command unvalidated motion directly. |
| RP-06 final closure | After relevant RP-01/RP-02/RP-05 evidence | Layout must reflect measured mass, power, heat and acoustic evidence. |
| RP-07 following | Documentation, corpus design, replay tooling and motors-inhibited perception may begin immediately; head-only work needs the safe RP-01 head; floor authority waits for RP-03 safety and required RP-04 coordination gates | Follow the RP-07 ladder: replay → live/no-motion → head-only → guarded low-speed → come → follow → adverse/fault. |

Parallel work is allowed only when it does not consume the same unsafe rig, depend on an unresolved upstream assumption, or hide the project's mechanical/firmware priority beneath familiar software work.

## Portfolio stop and escalation rules

Stop the active test immediately for unexpected unbounded motion, fixture movement, threatened fall, damaged insulation/cable, smoke/odour/swelling, component temperature beyond the registered limit, repeated unexplained reset, failed physical isolation, or any condition outside the reviewed hazard envelope.

A Core prototype that misses its gate produces an iteration, alternative candidate, architecture change, or explicit foundation review—not a quiet scope reduction. A Candidate may be deferred.

## Decision closeout

After each prototype:

1. publish and review its minimum evidence packet;
2. record gate results without deleting failed attempts;
3. update the affected engineering-budget rows with measured value, uncertainty and margin;
4. append or update the relevant ADR decision record with options, trade-offs, evidence and revisit trigger;
5. update requirement thresholds only where the approved foundation delegates them;
6. update sourcing/cost and physical-envelope ledgers;
7. identify which downstream prototype assumptions changed;
8. decide pass, bounded iteration, candidate rejection, or optional deferral.

## Open inputs before RP-01 scored testing

- [x] Approve `workbench.md` as the Stage 0 sourcing and powered-test-readiness baseline.
- [ ] Establish access to the required tools and fit/verify the selected stop/isolation method.
- [x] Select at least two credible head-mechanism concepts or document why only one survives calculation/sourcing. (Concept A selected; builder waived Concept B before fabrication, recorded in HEAD-CAD-09.)
- [x] Create the first sourced head component/envelope and representative mass target. (`dimensional-baseline.md` v1.2 + `mass-envelope-ledger.md` v0.4 + `candidate-sourcing-matrix.md` v0.4)
- [ ] Draft the motion storyboard and register the required roll/pitch/yaw cases.
- [ ] Correct/recheck Layout-03 screw collisions and hard-stop margin; select bearing geometry; document physical balance trim and storyboard↔CAD/firmware sign mapping.
- [ ] Stiffen and verify the loaded pitch frame and roll saddle against the authored modal targets; bound actuator rotor/gear acceleration demand before paper passage.
- [ ] Complete RP-01 numeric gates for range, reversal, repeatability, tracking, settling, noise, temperature, endurance and fault response.
- [ ] Clamp the RP-01 fixture and verify its E-stop and limits per the `workbench.md` scored-test gate.
- [x] Define the run-ID, configuration identity and evidence-storage convention. (`run-record-convention.md` v1.0)
- [ ] Define and implement the machine-readable logging schema and pre-run write check.
- [ ] Define and validate the monotonic timebase and external-video synchronization method. (Strategy documented in `timebase.md` v0.2; validation is RP02-G05.)

## Approval note

Approved by the project builder on 2026-08-17. Approval adopts the seven-prototype portfolio, roadmap, dependency order, threshold-registration policy, evidence-packet requirements, pass/iterate/reject/defer model, Core-failure rule, and decision-closeout process as the V1 risk-reduction baseline. Version 1.2 (2026-08-22) removes the per-prototype planning time boxes; iteration control is exercised through the gate-outcome review rule rather than calendar estimates. Version 1.3 (2026-08-25) consumes the selected dimensional/drive baseline and adds its CoM, caster-lift, skid, and forward-acceleration validation inputs to RP-03. Version 1.4 (2026-08-27) records the first credible RP-01 mechanism candidate and tightens the axis/CoM, backlash-versus-modal, harness-restoring-torque, busy-minute thermal, and head/body IMU evidence methods; it selects no mechanism or actuator and freezes no numeric gate. Version 1.5 (2026-08-28) adds per-axis mass accounting, makes the roll-support/display section a Concept-A blocker, and replaces an endpoint “lost motion” proxy with loaded hysteresis plus hold-hunting evidence. Version 1.6 (2026-08-29) consumes the project builder's locked no-touch Waveshare ESP32-S3-LCD-4.3, SKU 30493, and makes RP-06 validate the layout around that exact module rather than rerun display selection.

Version 1.7 (2026-08-29) consumes the project builder's locked visible-light Raspberry Pi Camera Module 3 Wide, order code SC0874, and makes RP-01/RP-06/RP-07 validate that exact camera while keeping the supplier, body SBC and production moving interconnect open. Version 1.8 (2026-08-30) propagates the selected-component-derived 95 × 150 × 115 mm nominal head envelope and its 90–100 × 145–155 × 110–120 mm validation band into RP-01/RP-06 inputs. Version 1.9 (2026-09-02) closes the RP-01 C1/C2 fork in favour of a separate ESP32-S3 C2 motion controller, fixes the display-versus-trajectory ownership boundary, and replaces the obsolete 250 g load input with the ~490 g pre-M008 lower bound plus C2.

Version 1.10 (2026-09-08), by builder direction when RP-02 planning opened, gives RP-02 a separate design question and gate question, reshapes RP02-G02 into a standing coexistence invariant with a re-run rule owned by the new `power-energy-ledger.md`, reshapes RP02-G03 into a rehearsal with recorded margin whose requirement closes at SC-14, splits ADR-06 closure into an architecture half and a sizing half, adds the power/energy/thermal ledger and `timebase.md` as continuous-workstream deliverables, and staggers RP-02's start into phases so its paper and on-hand-hardware work can proceed while RP-01 is open. G01, G04, G05 and G06 are unchanged. No numeric threshold is registered by this version.

Version 1.11 (2026-09-12) propagates Layout 03 as the RP-01 planning baseline (104 × 150 × 115 mm; nominal 362/436/509 g roll/pitch/yaw at M008=20 g), retains 10/20/35 g M008 sensitivity until weigh-in, requires candidate-specific servo substitution, records Concept B's explicit waiver and removes the superseded 95 mm validation band. No numeric gate is registered and no physical evidence is upgraded.

Version 1.12 (2026-09-13) consumes the completed Layout 03 **external rigid-body** demand model and the first named RP-01 comparison candidate (XC330-M288-T, C01, paper OPEN). The same-day closure audit clarified that this is not complete electromechanical/structural proof: actuator-internal inertia, structural modes, two screw collisions, stop margin, trial bearing seats, physical balance trim and sign mapping remain open. Complete-head `W` mass remains blocked on M008. RP-02 Phase B may use C01 as a named reference load; PA-04 still collapses only on family freeze.

Version 1.13 (2026-09-19) consumes `dimensional-baseline.md` v1.12: V1 front support is the Ø1 inch ball transfer; the swivel caster is the RP-03 comparison swap. RP-03 rig geometry is 110 mm to front-support contact. No numeric gate is registered.

Version 1.14 (2026-09-21) replaces the leftover ~250 g moving-head target in the RP-06 mock-up procedure with the current Layout 03 D/E baseline (~499–524 g complete, nominal 509 g at M008=20 g), records the RP-06 evidence folder, and names the selected Pi 5 / Active Cooler as body mock-up content. No numeric gate is registered.

Version 1.15 (2026-09-21) relocates working prototype CAD into `docs/02-prototypes/RP-06-cad/`. RP-01 and RP-03 keep mechanism/physics/gates; their former `cad/` directories become forwarding stubs. No numeric gate is registered.

Except for the later-adopted dimensional/drive topology baseline, the selected no-touch Waveshare display SKU 30493 and the selected visible-light Raspberry Pi Camera Module 3 Wide SC0874, plan approval does not approve another exact component, supplier, mechanism implementation, production camera interconnect, or numeric `SC-TBD-*` or `CON-TBD-*` gate threshold. `workbench.md` was approved separately on 2026-08-17 and incorporated as the Stage 0 baseline in version 1.1 of this plan. Numeric prototype gates remain subject to preregistration before scored runs, and powered scored testing remains blocked until the approved readiness gate's safety, instrumentation, configuration, and logging requirements are satisfied.

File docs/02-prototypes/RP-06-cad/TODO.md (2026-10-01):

# RP-06 TODO

| Field | Value |
|---|---|
| Status | **Open.** Working CAD is head Layout 04 + body/chassis Layout 02. Physical validation 0% |
| Home | [`README.md`](README.md) |
| Detail | [`checklist.md`](checklist.md) |

Checking a box here does not freeze a SKU, promote `E` to `W`, or register a gate.

## CAD progress and largest remaining gaps (audit 2026-09-27)

Layout 02 is an integrated packaging model, not a fabrication release. The rear module now contains only the skid/TCRT keel. The full `check_layout.py` suite on the current source passes **115/115**; the keel guard seats along its length and the former PCB-03/motor connector-reserve overlaps are absent. The 2,551.9 g / X +19.46 / Z 107.27 mm mass and CoM figures come from a hand-kept register, not measured hardware.

Completed at the CAD packaging level:

- [x] Compose the active Layout 04 head with the body, chassis, wheels, motors, fixed ball nose, rear keel, shell, service panels, electronics, yaw stage, and inspection layers in one buildable STEP; regenerate the visual snapshot packet.
- [x] Establish the nominal 170 mm track, 84 mm wheels, 16 mm forward body shift, four-M4/two-pin body interface, service-panel outlines, and 293.5 mm neutral height. These are modeled dimensions, not as-built measurements.
- [x] Model the Pololu #4804-based motor face, flange, 608 bearing pair, stub shaft, dished-wheel clearance, battery tub, ball caster, front range sensor, speaker cavity, E-stop well, charge cut-out, and pack-disconnect service window.
- [x] Allocate working CAD positions and connector exits for the Pi 5/cooler, power boards, C3 carrier, audio boards, IMU, yaw junction, and head trunk. The custom boards and cables are still estimated envelopes or route volumes.
- [x] Clear the two previously reported PCB-03/motor connector-reserve overlaps and complete the full current-source geometry suite (115/115 on 2026-09-27).
- [x] Recheck the proposed +6.5 mm height addition against the current model (2026-09-27). The seated Pi 5 cooler STEP spans Z 94.35–108.57; `PI_COOLER_TOP_Z = 123` is a conservative clearance datum, 14.43 mm above its actual top. The neutral stack is already 293.5 mm against the rounded 300 mm target, so no height was added. The Pi reaches Z 111.9; PCB-05 spans Z 114–123 (2.1 mm above that top), its connector bodies reach Z 125.6, and the front upper cross begins at Z 126. Moving the tray and Pi up 6.5 mm would require redesign of those interfaces, plus a new dimensional-baseline decision. The cooler is still unretained and must be fitted on hardware.

Largest gaps, in order of impact on CAD closure:

1. [ ] **Prove the latest assembled geometry.** The full Layout 02 suite passes 115/115. Complete an all-group clash sweep, including the composed head, signal/sensor harness, yaw plate/upper rails, microphone boots, and wheel arches, then resolve unintended overlaps. The inherited Pi 5 vendor STEP also has five self-intersecting occurrences, so distinguish vendor topology defects from authored geometry. See the detailed check item and `openitems.md`.
2. [ ] **Reconcile the safety geometry with RP-03.** The current rear-only TCRT leaves no dedicated forward/lateral cliff channel, and objects below the GP2Y beam can reach the ball housing without a touch signal. Decide the sensing/contact coverage and operating limits, then propagate `RP03-CAD-01…08` into the permanent locomotion baseline before physical layout closure.
3. [ ] **Engineer the load-bearing and service joints.** Close the wheel-to-stub fixing and axial retention, motor-face diaphragm and chassis stiffness, bearing preload, yaw bearing/gear load path, Pi/cooler retention, wheel-arch attachment, battery hatch/retention, and fastener/insert stacks. Add material, tolerances, tool access, and joint checks; details are in “CAD gaps and inefficiencies” below.
4. [ ] **Replace envelopes with buildable boards and sourced parts.** Complete PCB-01…10 schematics/layouts where applicable, fit the real pack/BMS, power components, connector bodies, sensor breakout, audio hardware, and purchased yaw bearing. PCB-03/04 consume the available bay, and the working `PCB-03` connector-edge margin is only 0.4 mm; rerun fit checks against laid-out boards and measured articles.
5. [ ] **Complete and qualify the installed harness.** Convert route reserves to a wire/connector build with lengths, bend radii, strain relief, demate paths, pinouts, and the moving yaw/CSI clock-spring construction. Check cooler airflow and service access with the harness installed.
6. [ ] **Replace paper mass and fit with physical evidence.** Weigh the robot and head, recompute the neutral and head-pose CoM/lift margins, fit sourced parts, then register and execute RP06-G01…G06. The project currently records **0% physical validation**.

---

- [x] Neutral stack: **closed 2026-09-26.** Head Layout 04 cut the neck from 60 to 49.5 mm (turntable in place of the spindle), so the stack is 140 + 49.5 + 104 = **293.5 mm**, under the 300 mm target (`neutral_stack_is_documented_293p5_mm`, `neck_allocation_is_49p5_mm`). Registered in `dimensional-baseline.md` v1.13; physical height remains a G01 measurement.

- [x] (superseded by the item above; the target is met without it) Use the real Pi 5 cooler height: with the cooler seated on the SoC (top Z 107.5, not 123) the body's 10.5 mm cooler headroom has ~15 mm of slack. Re-derive the yaw stage / neck stack from `PI_SOC_TOP_Z` and see whether the 4 mm needed for the 300 mm target can be recovered (changes the head neck, the body-top datum and the CoM gap below).

- [x] Close the CoM gap (baseline revised, see below): Layout 02 is at x +20.6 / h 105.8 mm (a_tip 1.91 m/s²) with the 81.6 g ballast bar (`RP03-CAD-08`) that offsets the lighter 110 g battery (`RP03-CAD-07`); the target is +25 / 124. The +20 mm `physics.md` §2.5 line clears by only 0.62 mm. Recover the rest by geometry or revise the baseline; the ballast screws' thread engagement in the deck and the bar's mass are unverified.
  - **Resolved 2026-09-25 (`RP03-CAD-09`, `BA-06`):** the builder accepted the then-current layout-02 register with the power boards, x +18.77 / h 105.05 mm (a_tip 1.75 m/s²), instead of +25 / 124. The 81.6 g `RP03-CAD-08` bar stays; no additional ballast was added. The `physics.md` §2.5 check is re-based from x ≥ +20 mm to the a_tip 1.582 m/s² that line encodes at h = 124 mm. The latest generated mass register is 2,551.9 g, x +19.46 / h 107.27 mm, a_tip 1.78 m/s²; the 2026-09-27 current-source suite passes 115/115. The earlier worst-head-pose figure of about 1.44 m/s² still needs recalculation against this register. Still open: a weighed robot (`W`) to replace the hand-kept register and head lumps

- [ ] Close the new axle stack (`RP03-CAD-05`) on real parts: ~~gearmotor face-screw pattern and shaft length~~ (in CAD from Pololu's drawing and STEP, `RP03-CAD-10`, 2026-09-26; confirm tapped length 2.85 mm, bushing boss and shaft on received #4804 samples), stub-to-web fixing and axial retention, bearing preload, deck/cheek stiffness, and the 2 mm printed diaphragm that now carries the motor face screws (stiffness and PETG creep under preload).

- [ ] Resolve the older body-side clashes the 2026-09-24 sweep found (harness power volumes against electronics: re-routed clear 2026-09-26; rear frame against power/safety envelopes, yaw plate and upper rails against the shell); see `openitems.md`.

- [ ] Resolve inherited RP-01 blockers:
  - [x] two screw collisions (closed 2026-09-25 in head Layout 04: 0.51 mm clearance, 30 fasteners in the 56-pose grid, 0 hits)
  - [ ] pitch-frame stiffness (redesigned 2026-09-25, FEA about 41 Hz; loaded tap/ring-down B6 open)
  - [ ] roll-saddle stiffness (redesigned 2026-09-25, FEA about 84 Hz; B6 open)
  - [ ] hard-stop margin (stops 3 deg past usable travel, Ø2 steel dowels; stop impact at speed is a bench item)
  - [x] bearing SKU (696-2Z selected 2026-09-25; trial fit and preload on printed seats open)
  - [ ] balance trim (trim path modelled 2026-09-25; weigh and trim on the built head)
  - [x] CAD/firmware sign mapping (closed 2026-09-25: `head/layout-04/motion-signs.json`, pitch +1, yaw -1, roll -1)
  - [x] actuator family: working choice `ACT-01` (2026-09-25), XC330-M181-T yaw, XC330-M288-T pitch/roll at 5 V (RP-01 `decision.md`). Not frozen: bench tests B1-B6 and dated builder approval remain
  - [ ] production camera interconnect

- [ ] Replace remaining CAD envelopes with exact vendor or measured geometry:
  - [ ] motors and gearboxes (vendor STEP for Pololu #4804 in since `RP03-CAD-10`; measured article pending the SKU lock)
  - [ ] wheels and hubs
  - [ ] ball-transfer article
  - [ ] battery: 2S1P Samsung 25R + BMS is modeled as datasheet envelopes (`RP03-CAD-07`); replace with the measured pack and the real BMS board
  - [ ] power modules
  - [ ] motor drivers
  - [ ] sensors (IMU now `PCB-07` from its datasheet, 2026-09-26; TCRT breakout and comparator still an envelope)
  - [ ] audio hardware (parts selected 2026-09-26 and modelled from datasheet outlines; measured articles pending)
  - [ ] connectors and cable exits: schedule and layout rule set 2026-09-26 in [`connector-schedule.md`](connector-schedule.md) (JST GH signals, Micro-Fit power on free board edges, re-crimped #4804 leads, USB-C Pi pigtail, rear charge-inlet cut-out, head trunk re-routed via a -Y yaw junction, Micro-Fit+ pack disconnect `CN-05`, C3 carrier `PCB-10` on the -Y wall `CN-06`). Open: Micro-Fit+ drawings, pin-outs, vertical USB-C inlet part, bench fit of the 0.1 mm Pi-header adapter strip

- [ ] Replace remaining boxed body-chassis Layout 02 parts with exact STEP or measured geometry (several vendor STEPs have been integrated since the 2026-09-24 audit; the detailed entries below distinguish imported parts from estimates):
  - [x] Wired into `body_chassis_model.py` from `layout-01/references/purchased/` (2026-09-24; 95/95 checks pass; STEP rebuilt, snapshots refreshed):
    - [x] `pololu_drv8874_carrier.step` (Pololu 4035; bare board 15.2 x 17.8 x 2.8 mm, no headers) replaces the 20 x 20 x 12 DRV8874 boxes; sits flat with its bottom on the old envelope floor (Z 66), mounting unspecified
    - [x] `vishay_tcrt5000.step` (10.2 x 7.1 x 10.5 mm incl. leads) replaces the 10.2 x 5.8 x 7.0 package box; keel sensor pocket and `TCRT_PACKAGE_SIZE` Y widened to fit (7.1 wide, 10.5 tall)
    - [x] `sharp_gp2y0a41sk0f.step` wired in (2026-09-24 prow rework): the 29.6 mm body and 44.4 mm belt now sit in side slots of a swelled pod; sensor bottom Z 35, lens tip X 128; cap window is a 27 x 10.5 visor slit
    - [x] `robotis_xc330_dummy_assy.step` (20 x 34 x 29 mm, 15 solids) replaces the yaw servo box; it is a third-party mirror (xiaoyatec.com) of ROBOTIS's XL/XC-330 file, so verify against the official ROBOTIS download once signed in. Oriented -90 deg about Z so the body runs along X (the +Y orientation hit the left upper rail); output axis on the pinion centre. Envelope Z height was 34, real stack is 29
  - [x] Login-gated STEPs, added by hand from GrabCAD and Digi-Key and now wired in:
    - [x] Raspberry Pi 5 active cooler: GrabCAD `raspberry-pi-5-active-cooler-1` / `raspberry-pi-5-stock-active-cooler-1`; official mechanical drawing PDF on Olimex RPi5-ACOOL resources. File `Heatsink+fan RPi-5.STEP` (64.8 x 14.2 x 43.5 mm). Seated 2026-09-24: spring posts in the Pi's two cooler holes (58 x 37 mm apart; the first -90 deg turn mirrored them), plate on the tallest package under it (Z 97.7), top at Z 107.5. The old envelope floated the cooler 11 mm too high, so the 10.5 mm yaw headroom datum (`PI_COOLER_TOP_Z` 123) is now ~15 mm conservative
    - [x] ESP32-S3-DevKitC-1-N8: Digi-Key model page 15295894 (the listing is N8R8; the model uses N8, confirm the board outline matches). File `ESP32-S3-WROOM-1_devkit_2xUSBC_c.step` is 28.3 x 64.1 x 5.5 mm (no headers), wider than the old 25.4 mm envelope; USB end rearward; confirm it is the N8 board
  - [ ] CAD not found, use a vendor drawing or measure:
    - [x] Pololu ball caster 1" with plastic rollers (item 2691): no vendor STEP; authored from the dimension drawing with Ø14.1 mm bolt circle after correcting the 12.2 mm hole-spacing misread. Measured fit, screws and ABS thread engagement remain open below.
    - [x] Gearmotor: switched to the preferred Pololu #4804 and wired in its official STEP (`pololu_25d_34-47_encoder.step`, 2026-09-26, `RP03-CAD-10`); axle stack rebuilt round its face, leads clocked rearward. The 110/110 pass was a historical run, before later connector changes; rerun the current model. The JGA25-370 community STEP is no longer needed
  - [x] Head STEPs wired into head Layout 04 (2026-09-24); files in `head/layout-01/parts/`; head checks pass, dimensions and assembly reports regenerated:
    - [x] `waveshare_esp32_s3_touch_lcd_4_3.stp` for the display. SKU 30493 is the non-touch board (105.4 x 67.1 mm); the Touch STEP (106.1 x 68.3 x 16.9 mm) is used as the conservative outline, glass front on X -3.8. Fit checks use a slab plus connector-strip proxy (12.5 mm deep, 16.9 mm over one 5 mm strip on the -Y edge). Still open: replace with the non-touch model if Waveshare publishes one
    - [x] `waveshare_esp32_s3_zero_v2.step` for C2 (18.0 x 23.5 x 1.9 mm, bare PCB: the STEP has no USB-C shell or headers, so the authored USB reserves stay). Components face -X
  - [x] Ball caster: Pololu 1" caster 2691 (rollers; 2692 is the bearing variant, same envelope). India: Fab.to.Lab (bearings +₹337), MG Super Labs (₹399 incl. GST). Indian industrial ball-transfer units (25.4 mm, ₹105-125) are 130-220 g steel with 14-21 mm working height, so they do not match. The hole pattern was misread: Pololu's 12.2 mm is the spacing between holes, so the bolt circle is O14.1 (radius 7.04, model had 12.2), base O34 x 8.8 (model had O36 x 4). STEP authored by `build_ball_caster_step.py` into `purchased/pololu_ball_caster_1in_2691.step`; the supplied `Pololu Ball Caster.STEP` is the 3/8" caster (9.5 mm ball) so it was used as a structural template only. Still open: verify screw length and thread engagement on a real unit, and ABS thread-forming vs. inserts in the base
  - [ ] Fasteners are authored cylinders; real STEPs exist on step.parts (ISO 4762 M3/M4/M2, ISO 7380, M3 heat-set insert bosses, M3 nuts). Only worth swapping once head/body fastener SKUs are chosen (P-07)
  - [ ] Ball caster form check: the CAD is a form match to the Pololu photo (dome shoulder, roller windows, rim notch, snap slits), built from the vendor drawing, not a scan. When a sample 2691/2692 arrives, caliper the base O.D., roller-window positions, notch width, slit positions and the real bolt circle, then update `build_ball_caster_step.py`. Note the photo shows the 2692 bearing version; the model uses plain rollers.
  - [ ] SKU not chosen, so nothing to download yet:
    - [x] ICM-42688-P IMU: own `PCB-07` board screwed to the chassis deck crossbar, modelled (`RP03-CAD-11`); bench article any SPI+INT1 breakout, MIKROE-4237 where stocked ([`peripheral-selection.md`](peripheral-selection.md) §4)
    - [ ] yaw thin-section bearing (50 g placeholder in `MASS_ROWS`)
    - [x] speaker, amplifier and four PDM microphones: selected and modelled from vendor outlines (2026-09-26); no vendor STEP read, the speaker's internal profile is estimated
    - [ ] power-distribution and safety/watchdog boards (RP-02); the battery is working-selected (2 × Samsung INR18650-25R + 2S 20 A balanced BMS), with no STEP for the BMS board
    - [ ] harness: modeled as volumes, not parts. Head trunk re-routed 2026-09-26 (plate bore, -Y junction `PCB-08`, -Y riser; CSI FFC beside the cooler); [`connector-schedule.md`](connector-schedule.md) now lists wire IDs, functions, conductors and tentative lengths, but final lengths, pinouts, bend/strain relief and moving-cable construction remain open.

- [ ] Resolve the RP-03 CAD-versus-safety issue:
  - the controller/safety design expects multiple direct stop-path sensors
  - current Layout 02 only packages one guarded rear TCRT channel and explicitly makes no full forward/lateral cliff-protection claim
  - since the touch-cap skirt cut (`RP03-CAD-04`, 2026-09-24), floor objects below the GP2Y beam (Z 41), including `C12`, meet the ball's retaining lip with no contact signal; forward edges and low obstacles now rely on the camera, which is not a low-level stop channel
  - this must be reconciled before physical layout closure

- [ ] Complete an all-group sweep of the composed head and body-side groups. The current full Layout 02 geometry suite passes **115/115**. The rear keel guard was shortened 2 mm at its forward end and now seats along its length, ending 0.1 mm behind the TCRT package front; the former PCB-03/motor Micro-Fit reserve overlaps are clear in the current report.

- [x] Replace the six misplaced `_vertical_bore` calls with bottom-aligned `_z_cylinder` (2026-09-26). Targeted cylinder extent checks pass; the STEP was rebuilt and the visual snapshot packet refreshed. Full-assembly check completion remains tracked above.

- [ ] Close the ball-nose touch cap on real parts: flexure stiffness, tact-switch force and over-travel stop, debounce, and the 3 mm travel.

- [ ] Confirm the GP2Y 0.70 m/s look-ahead on real floors: charged to the nose front it needs 294.5 mm against the 300 mm rating.

- [ ] Propagate `RP03-CAD-01`…`08` to the permanent RP-03 documents as one reviewed change set (sensor count, bump coverage, the fixed ball-only mount versus the required `D20` swap, CoM and motion restrictions).

- [x] Select the status LED and diffuser/optic. **Working selection 2026-09-26** ([`peripheral-selection.md`](peripheral-selection.md) §3, `HEAD-CAD-12`): Worldsemi WS2812B-2020-V6 on a 5 × 5 mm carrier (`PCB-11`) behind the unchanged Ø3.4 × 2.9 light pipe (clear resin or PMMA, frosted face), D1 GPIO6 at 3.3 V. Still open: route the three leads from the crown to D1, bench brightness at 3.3 V and camera stray light (G03).

- [x] Select microphone front end, microphone boards, speaker, and amplifier. **Working selection 2026-09-26** ([`peripheral-selection.md`](peripheral-selection.md) §2, RP-05 `BD-A04`…`A06`, `RP03-CAD-11`): `AP-TDM` as two I²S lanes on the Pi 5 (RP1 has no true TDM), 2 × ADAU7002 and a MAX98357A on `PCB-05`, four Infineon IM73D122V01 on `PCB-06` boards at the unchanged ports, Visaton K 50 WP 8 Ω. Modelling them showed the old amplifier box sat inside the Pi 5 and the 34 mm cavity ran through the compute tray, so `PCB-05` moved above the Pi's front end and the cavity is now 20 mm (X 77–97). Still open: `CA-06` CR-01 (GPIO22 SDI1, GPIO23 `AMP_SD`), the Pi 5 overlay and duplex bench proof, mic-board fixing to the body frame, speaker flange bond and grille, acoustic tests.

- [ ] Finish the battery and power-hardware selection against real parts. The 2S1P Samsung 25R pack, Micro-Fit+ 1×2 disconnect, fuse tile and estimated board envelopes are working CAD choices. Open: exact connector/terminal drawings and ratings, pack retention and hatch fastening, board layouts, and who builds the pack (workbench battery gate). The power-board spec is v0.17; estimated CAD envelopes cannot prove the laid-out boards fit.

- [ ] Design the small boards the 2026-09-26 selections created ([`peripheral-selection.md`](peripheral-selection.md)); none has a schematic:
  - [ ] `PCB-05` audio front end (2 × ADAU7002 WLCSP, MAX98357A TQFN, 100 Ω series on the amp inputs, JST GH mic inputs (`CN-01`)); JLCPCB assembly because of the WLCSP
  - [ ] `PCB-06` mic board ×4 (IM73D122V01, Ø0.8 port hole, LR strap per position, JST GH 4-pin, board 12 x 9.5 mm; `CN-01`) and its fixing to the body frame
  - [ ] `PCB-07` IMU board (ICM-42688-P, JST GH 8-pin (`CN-01`), two M2 holes 15 mm apart)
  - [ ] `PCB-11` LED carrier (WS2812B-2020, three pads)
  - [ ] Raise `CA-06` CR-01 in RP-02 (GPIO22 `i2s0` SDI1, GPIO23 `AMP_SD`) and prove the custom `simple-audio-card` overlay: 4-channel capture on SDI0+SDI1 with 2-channel playback on SDO0 at 48 kHz, lane order, and whether RP1 forces symmetric channel counts

- [ ] Obtain or fabricate representative articles and measure:
  - [ ] every relevant mass
  - [ ] complete robot CoM
  - [ ] head installed mass/CoM
  - [ ] service clearances
  - [ ] cable bend and demate volumes
  - [ ] airflow and temperatures

- [ ] Perform the physical display tests:
  - [ ] smoked window
  - [ ] viewing angle
  - [ ] distance
  - [ ] lighting
  - [ ] frame rate and tearing

- [ ] Perform camera tests:
  - [ ] FOV and occlusion
  - [ ] calibration
  - [ ] focus lock
  - [ ] motion smear
  - [ ] LED/display contamination
  - [ ] live CSI endurance

- [ ] Perform audio tests:
  - [ ] speaker level and vibration
  - [ ] microphone contamination
  - [ ] cooler and mechanism noise
  - [ ] playback-while-listening behaviour

- [ ] Demonstrate replacement of a named high-risk module and record time/tools.

- [ ] Verify current suppliers, landed costs, and substitutes.

- [ ] Register and execute RP06-G01…G06.

## CAD gaps and inefficiencies

Running list of ways the current CAD falls short of a production design. Add to it as they turn up.

- [ ] Layout 02 is a packaging and fit-check model, not a production design (noted 2026-09-24). Passing checks means no clashes and the clearances hold, not that the design is complete. Open causes:
  - [ ] Pi 5 and active cooler have no retention: no standoffs, cooler push-pins or fasteners, and the compute tray is a plain 3 mm box. The cooler is only positioned (`PI_COOLER_TOP_Z`), and nothing ties it to the Pi
  - [ ] Check underside clearance for the cooler push-pin tips and the Pi-to-tray standoff gap (currently an assumed ~16 mm)
  - [ ] Check fan intake and airflow: only 10.5 mm of headroom over the cooler under the yaw stage
  - [ ] Yaw-stage parts are packaging envelopes, not selected or load-rated parts
  - [ ] Head-harness route: no longer through the compute tray and cooler (2026-09-26, check `head_trunk_and_csi_avoid_tray_pi_cooler_and_yaw_stage`); the clock-spring, `PCB-08` junction and cable qualification remain open

- [ ] Wheel arches and trim have no attachment (noted 2026-09-24). `WHEEL_ARCH_POD_L/R` and the amber `WHEEL_ARCH_UPPER_TRIM_L/R` are separate solids under `BODY_PANELS`, not part of `BODY_SHELL`, and nothing fixes them in place: no screws, tabs, bosses or adhesive land, and no snap or bond for the trim on the arch.
  - [ ] Decide the concept: integral flanges in the printed shell, or bolt-on fenders fixed to the chassis cheeks. The shell floor is open across the axle so the body lowers on from above, which rules out a simple bond
  - [ ] The arches are X-centred on the axle (0.0), not on the body, so they don't follow `BODY_SHIFT_X` (16 mm). Confirm that's intended
  - [ ] Measure the arch-to-shell overlap or gap, and whether the arch sits inside or outside the shell wall; it is part of the open panel-versus-shell clash sweep
  - [ ] Add the fixing and its clearances to the checks

- [ ] Fasteners are positions and bores, not engineered joints (noted 2026-09-24). `CON-P01` (`00-foundation/constraints.md`) makes screw-together construction a requirement for serviceability, and `brief.md` leaves "thread engagement, inserts, sealing/gasket detail, tolerances, material/process selection and structural proof" unresolved. The checks cover screw count, edge inset and ball-flange thread engagement (>= 2.5 mm), not load or stiffness. To do:
  - [ ] List every joint (M4 body/chassis through-bolts and locating pins, M3 service panels, ball flange and pod, keel, axle flange, yaw stage, arches) with its screw, insert or nut, clamp stack, and load path
  - [ ] Set thread engagement and boss geometry per joint: heat-set insert depth, boss wall, edge distance, pull-out margin
  - [ ] Add clearance holes, counterbores, captive nuts or inserts, and washers where the joint needs them, so the CAD carries what would be bought and machined
  - [ ] Size for preload, shear and stiffness on the load-bearing joints first: axle flange, body/chassis bolts, yaw plate and bearing
  - [ ] Choose the material and process (printed, machined or moulded), then the tolerances and any gasket or seal
  - [ ] Add per-joint checks: engagement, edge distance, tool access and service removal path
  - [ ] Add a fastener schedule (BOM) to the generated outputs

## Custom power and safety boards

Spec: [`../RP-02-electrical/board-specs.md`](../RP-02-electrical/board-specs.md) v0.17, 2026-09-25 (working direction, **not registered**; decisions `BD-01…14`). Four custom PCBs plus a watchdog block: `PCB-01` pack protection, `PCB-02` charge and system power, `PCB-03` motor gate and head/drive distribution, `PCB-04` branch converters. Part choices, values and estimated packaging envelopes are in CAD; schematics, layouts, selected connector parts and bench proof are open. Nothing here selects a SKU for purchase.

- [x] Part choices on paper (working choices, 2026-09-25; each is a datasheet-derived proposal, none bench-proved):
  - [x] `PCB-01`: `S-8252AAC` + `bq29200`, two `PSMN1R5-30YLC`, 5 mOhm Vishay `WSK2512` shunt, Bourns `AC72ABD` thermal cutoff
  - [x] `PCB-02`: `BQ25798` in default mode (no host), `STUSB4500` (5/9/15 V at 1.5 A), `LTC2954-2` latch, `SYS` gate `TPS22810`
  - [x] `PCB-03`: `LTC4368-1` + 3 mOhm shunt + two `PSMN1R0-30YLE`, `SMBJ10A` TVS; head rail `LTC3119` behind a latching `TPS259824`
  - [x] `PCB-04`: `TPS630701` + `TPS259474L` per branch; Pi rail `LTC3119`
  - [x] Watchdog: `TPS3436CFDBEDDFRQ1` per C2/C3 carrier
- [x] Place C3 carrier `PCB-10` in CAD (`CN-06`, 2026-09-26): 70 × 43.5 mm, vertical on the -Y side wall, DevKitC soldered on, ten installed GH headers plus one Micro-Fit 3.0, and four M2.5 screws into printed uprights on the -Y rails. `J10-9` was dropped when the touch switch joined `J10-8`.
- [ ] Finish `PCB-10` for fabrication: schematic after the RP-03 pin map freeze, real board layout, upright/insert strength, exact connector fit, and harness lengths.
- [ ] Decisions waiting on the builder (details in `board-specs.md` section 10): Pi setpoint 5.10 V vs 5.15 V; `PA-14` wording for the 43-100 uA `OFF` draw; ~~servo family~~ (settled 2026-09-25: XC330 at 5 V, RP-01 `ACT-01`); brownout threshold registration; purchase.

- [ ] Draw the schematics (start with `PCB-01`), then layouts:
  - [ ] Heavy copper and a short loop for the gate, shunt and drive feed on `PCB-03`; motor return straight to the star point
  - [ ] Keep the charge-logic net away from `PCB-03`; keep noisy converters away from C2/base converters and sense lines
  - [ ] Test points on every rail, branch current, gate state and each `MOTOR_PERMIT` term
  - [ ] `PCB-01` FET land pattern and an assembly route if the chip-scale alternate is used (the selected LFPAK56 parts are hand-solderable)

- [x] Give the boards estimated CAD volumes from the unlaid-out part inventory (`board-specs.md` section 2): `PCB-01` on the pack, `PCB-02` on the rear-panel frame, `PCB-03` above the battery tub, `PCB-04` under the compute tray. The connector and harness revisions moved the original clashes. Replace these envelopes with actual laid-out boards and rerun the fit sweep before release.
  - [ ] Check the `PCB-04` hold-up capacitors and connector exits in a real layout; the bay has little slack.
  - [x] Pack interface placed 2026-09-26 (`CN-05`, [`connector-schedule.md`](connector-schedule.md)): Micro-Fit+ 1×2 wire-to-wire pair beside the tub (X 27–49), ATOF holder moved next after it (X 51–75), service window in the +Y tub wall. Open: Molex outline and terminal rating, the bench service move, the pack NTC break
  - [x] The rear-panel E-stop is modelled: IDEC XA1E-BV3U02KT-R (Ø29 mushroom, 23.9 mm deep) in an 8 mm octagonal well with an amber bezel, replacing the Ø40 XW1E (2026-09-25)
  - [x] Rear-panel USB-C charge-inlet window is cut as a 13.2 × 7.2 mm envelope; select the actual receptacle and check tool/plug access.
  - [x] `CONTROL_POWER_SENSORS` was split into per-board mass rows, the E-stop changed to the 14 g XA1E, and the battery row was revised for the pack-side Micro-Fit+ half. The current hand-kept total is 2,551.9 g; verify on weighed hardware.
  - [x] The accepted CoM screen is a_tip ≥ 1.582 m/s², with the RP03-CAD-08 bar retained. Current estimate is x +19.46 / h 107.27 mm, a_tip 1.78 m/s². Recheck the pose corners and weigh the robot.

- [ ] Replace estimated power-hardware geometry with selected part drawings, vendor STEP and laid-out PCB geometry: `LTC3119`, `PSMN1R5-30YLC`/`PSMN1R0-30YLE`, `TPS630701RNMR`, `TPS259474L`/`TPS259824`, `BQ25798RQMR`, vertical USB-C receptacle, Micro-Fit+ pack disconnect and board connectors, ATO FLR fuse holder `178.6165.0001`, IDEC `XA1E-BV3U02KT-R`, `AC72ABD`, `WSK2512`/`CSS2H-2512`, and `XAL5030-332ME`. The DRV8874 carrier STEP is already imported.

- [x] Resolve the head-servo dependency. **Resolved 2026-09-25 as working choice `ACT-01`** (RP-01 `decision.md`): XC330-M181-T yaw, XC330-M288-T pitch/roll on the 5 V `PB-HEAD` rail, Dynamixel 2.0 over TTL half-duplex; 7.4 V and 12 V classes rejected for V1. The family is not frozen until bench tests B1-B6 pass. Original note: RP-01 had not frozen the family. The head rail is designed for the 5 V XC330 case (M181 yaw, M288 pitch/roll); a 7.4 V-class servo would be direct-fed, change the bus to Feetech half-duplex TTL, and runs into the 8.4 V versus charger worst-case conflict above. A 12 V variant would force 3S and reopen the pack, tub and charger.

- [ ] Yaw cable across the joint (`board-specs.md` section 9):
  - [ ] Confirm loop length, cycle targets and the life assumption (placeholders: 1 m loop, 3 years); the sideband list grew to about 14-20 AWG28 conductors
  - [ ] CSI FFC vs the O14 mm disc bore: the Camera Module 3's 15-pin FFC is 16.0 mm wide and does not pass flat; order the Raspberry Pi PCN-36 revision of the 15-to-22-pin cable (11.5 mm wide, 1.25 mm per side), and check its bend life in the clock-spring
  - [ ] Route it in CAD as a clock-spring (bending, not a straight twist; a straight bundle needs about 288 mm free length for +-55 deg at 1% strain)
  - [ ] Build and run the qualification: 10^6 cycles at +-15 deg, 10^5 at +-40 deg, 10^4 at +-55 deg plus over-travel at 378 deg/s, logging loop resistance, CSI, UART and servo-bus errors

- [ ] Drive stage (`BD-02`): [gearmotor SKU lock remains open](../RP-03-locomotion/gearmotor-sku-decision.md). Pololu #4804, HP 6 V / 34.014:1 / encoder is the preferred prototype candidate (290 rpm no-load, 240 rpm at 0.127 N·m maximum-efficiency point, 6 A extrapolated stall). Fab.to.Lab lists #4804 in India, but exact-variant stock and quantity need confirmation. ~~Reconcile the 12.5 mm shaft and 67 mm body with the CAD~~ (done 2026-09-26, `RP03-CAD-10`). Get a written Fab.to.Lab quote naming the current #4804 revision: their page carries older figures (280 rpm, 6.5 A) and a wrong CPR. Proposed DRV8874 limit about 3 A (about 0.30 N·m, and it also caps regeneration at 3 A). Read the DRV8874 carrier's current-limit resistor (the Pololu page gives both 3.5 A and 4.4 A); set and verify a launch-compatible limit before bench power, then verify C3 motor-terminal voltage/speed clamp on the 8.4 V bus.

- [ ] **Regeneration limit (new hard requirement, `board-specs.md` sections 5.2.4 and 5.3):** the cells' maximum charge is 4 A, so the drive stage must hold regeneration into the bus to 3 A or less and to zero below 0 degC (brake, not coast). Nothing enforces it yet; it belongs to the DRV8874 current limit and the C3 braking policy (RP-03).

- [ ] Measure before relying on any number: pack loaded sag against state of charge (cold and aged), a measured 25R voltage curve, real head and drive currents, `LTC3119` output current at 5.4 V and thermal at 3 A, converter behaviour at the low line, brownout thresholds, hold-up capacitance and discharge time.

- [ ] Promote `board-specs.md` decisions (`BD-01…14`) to the registered RP-02 documents only after the above closes, and fix the candidate-screen outcome table where it still describes items superseded by addenda.

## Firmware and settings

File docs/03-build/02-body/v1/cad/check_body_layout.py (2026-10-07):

"""Audit body-v1 mass, axes, envelope and the current stability screen.

This uses the printable CAD solids rather than the old Layout 02 shell/frame
allowances. It is an estimate until the selected print process and hardware are
weighed. Fit and assembly paths have their own checks beside this script.
"""

from __future__ import annotations

import json
import math
from pathlib import Path

import body_v1_model as M


HERE = Path(__file__).resolve().parent
PETG_SKIN_G_CM3 = 1.20  # near-solid 2.4 mm walls and conservative frame estimate
PETG_ARCH_G_CM3 = 0.571  # same effective infill-density assumption as chassis
STEEL_G_CM3 = 7.85
BRASS_G_CM3 = 8.50
PHYSICS_MARGIN_A_TIP_MIN = 9.81 * 20.0 / 124.0


def properties(items):
    """Mass, mass centroid, and vertical-axis inertia about the ground origin."""
    rows = []
    for shape, density in items:
        mass = shape.volume * density / 1000.0
        centre = shape.center()
        izz = (shape.matrix_of_inertia[2][2] * density / 1000.0
               + mass * (centre.X**2 + centre.Y**2))
        rows.append((shape.label, mass, (centre.X, centre.Y, centre.Z), izz))
    total = sum(row[1] for row in rows)
    com = tuple(sum(row[1] * row[2][axis] for row in rows) / total for axis in range(3))
    return {
        "mass_g": total,
        "com_mm": com,
        "yaw_inertia_about_ground_origin_g_mm2": sum(row[3] for row in rows),
        "components": [
            {"name": name, "mass_g": mass, "com_mm": centre}
            for name, mass, centre, _ in rows
        ],
    }


def main():
    shell = M.body_shell()
    panels = M.body_panels()
    panel_mount = M.panel_mount_hardware()
    frame = M.body_primary_frame()

    shell_items = [(shell, PETG_SKIN_G_CM3)]
    shell_items += [
        (part, PETG_ARCH_G_CM3 if part.label.startswith("WHEEL_ARCH_") else PETG_SKIN_G_CM3)
        for part in panels.children
    ]
    shell_items += [
        (part, PETG_SKIN_G_CM3) for part in panel_mount.children
        if "FRAME_WITH_BOSSES" in part.label or "WEDGE_WASHER" in part.label
    ]
    printed_frame_items = [(part, PETG_SKIN_G_CM3) for part in frame.children]
    frame_items = list(printed_frame_items)
    for group in (M.body_chassis_mount_hardware(), M.body_frame_joint_hardware(),
                  M.shell_frame_hardware()):
        frame_items += [
            (part, BRASS_G_CM3 if "NUT" in part.label or "INSERT" in part.label else STEEL_G_CM3)
            for part in group.children
        ]

    shell_props = properties(shell_items)
    printed_frame_props = properties(printed_frame_items)
    frame_props = properties(frame_items)
    yaw_parts = [*M.body_yaw_stage().children, *M.yaw_drive_moving_parts()]
    yaw_shell_clashes = {}
    for part in yaw_parts:
        intersection = shell & part
        volume = 0.0 if intersection is None else intersection.volume
        if volume > 0.001:
            yaw_shell_clashes[part.label] = volume
    register = {row[0]: row for row in M.MASS_ROWS}
    robot = M.mass_properties()
    x, y, z = robot["com_mm"]
    a_tip = 9.81 * x / z
    ball_share = x / M.BALL_CONTACT[0]
    com_cross_pitch = math.degrees(math.atan2(x, z))
    head_mass = M.HEAD_MASS_G
    head_yaw_local = M.HEAD_LOCAL_COM
    yaw_radius = math.hypot(head_yaw_local[0] - M.HEAD_LOCAL_YAW[0], head_yaw_local[1])
    head_mass_tree = json.loads((M.HEAD_DIR / "mass-placement.json").read_text())
    pitch = head_mass_tree["working"]["pitch"]
    roll = head_mass_tree["working"]["roll"]
    axes = head_mass_tree["axes"]
    pitch_offset = math.hypot(pitch["center_mm"][0] - axes["pitch_x"],
                              pitch["center_mm"][2] - axes["pitch_z"])
    roll_offset = math.hypot(roll["center_mm"][1] - axes["roll_y"],
                             roll["center_mm"][2] - axes["roll_z"])
    # Any rotation can move its mass centroid by at most twice its radius from
    # the axis. Include those small shifts in a conservative yaw/pose bound.
    pitch_roll_x_bound = (2 * pitch["mass_g"] * pitch_offset
                          + 2 * roll["mass_g"] * roll_offset) / robot["mass_g"]
    head_x_min = M.BODY_AXIS_X - yaw_radius
    yaw_x_shift = head_mass * (head_x_min - register["HEAD_V1"][2][0]) / robot["mass_g"]
    worst_pose_x = x + yaw_x_shift - pitch_roll_x_bound
    worst_pose_z = z + pitch_roll_x_bound
    worst_pose_a_tip = 9.81 * worst_pose_x / worst_pose_z
    harness_row = register["HARNESS_AND_FASTENERS"]
    harness_mass, harness_x = harness_row[1], harness_row[2][0]
    required_ratio = PHYSICS_MARGIN_A_TIP_MIN / 9.81
    harness_min_x = harness_x + robot["mass_g"] / harness_mass * (
        required_ratio * worst_pose_z - worst_pose_x)
    harness_rear_x_scenario = -20.0
    harness_rear_a_tip = 9.81 * (
        worst_pose_x + harness_mass * (harness_rear_x_scenario - harness_x) / robot["mass_g"]
    ) / worst_pose_z
    # Measure the actual chassis-v1 skid shoe at the ground datum.
    skid_shoe = M.rear_skid_tcrt_module().children[0].children[1].children[0]
    skid_angle = min(math.degrees(math.atan2(vertex.Z, -vertex.X))
                     for vertex in skid_shoe.vertices() if vertex.X < 0.0)

    def matches(name, measured):
        _, mass, centre, _ = register[name]
        return abs(mass - measured["mass_g"]) < 0.1 and all(
            abs(centre[i] - measured["com_mm"][i]) < 0.11 for i in range(3)
        )

    checks = {
        "shell_and_panels_match_mass_register": matches("BODY_SHELL_AND_PANELS", shell_props),
        "frame_and_joints_match_mass_register": matches("BODY_PRIMARY_FRAME", frame_props),
        # D-042: the +Y fan-intake grille and collar make the shell slightly asymmetric.
        "shell_symmetric_about_y": abs(shell.center().Y) < 0.5,
        "head_yaw_axis_unchanged": M.HEAD_YAW_DATUM == (16.0, 0.0, 140.0),
        "head_sweep_above_shell": M.HEAD_SWEEP_FLOOR_Z - M.BODY_Z_TOP >= 15.0,
        "yaw_stage_and_moving_parts_clear_shell": not yaw_shell_clashes,
        "mount_pattern_unchanged": set(M.BODY_MOUNT_POINTS) == {(-22.0, -48.0), (-22.0, 48.0), (64.0, -48.0), (64.0, 48.0)},
        "body_width_within_205_mm_baseline": 2 * max(station[3] for station in M.SHELL_STATIONS) <= 205.0,
        "com_between_axle_and_ball": 0.0 < x < M.BALL_CONTACT[0],
        "forward_tip_margin_screen": a_tip >= PHYSICS_MARGIN_A_TIP_MIN,
        "head_pose_tip_margin_screen": worst_pose_a_tip >= PHYSICS_MARGIN_A_TIP_MIN,
        "ball_share_above_spin_walk_flag": ball_share >= 0.09,
        "skid_contacts_before_com_crosses_axle": skid_angle < com_cross_pitch,
        "com_below_head_yaw": z < M.HEAD_YAW_DATUM[2],
    }
    payload = {
        "scope": "body-v1 source geometry and whole-robot estimated mass register; neutral head pose",
        "assumptions": {
            "petg_skin_and_frame_g_cm3": PETG_SKIN_G_CM3,
            "petg_arch_effective_g_cm3": PETG_ARCH_G_CM3,
            "steel_g_cm3": STEEL_G_CM3,
            "brass_g_cm3": BRASS_G_CM3,
            "mass_is_estimated_not_weighed": True,
        },
        "shell_and_panels": shell_props,
        "printed_frame_only": printed_frame_props,
        "frame_and_joints": frame_props,
        "whole_robot": {
            **robot,
            "forward_tip_acceleration_m_s2": a_tip,
            "forward_tip_screen_min_m_s2": PHYSICS_MARGIN_A_TIP_MIN,
            "ball_static_share": ball_share,
            "com_over_axle_pitch_deg": com_cross_pitch,
            "rear_skid_first_contact_pitch_deg": skid_angle,
            "reverse_launch_or_forward_brake_tip_acceleration_m_s2": 9.81 * (M.BALL_CONTACT[0] - x) / z,
            "axle_line_lateral_tip_proxy_m_s2": 9.81 * (M.TRACK / 2.0 - abs(y)) / z,
            "neutral_spin_centripetal_at_220_deg_s_m_s2": math.radians(220.0)**2 * x / 1000.0,
            "head_pose_conservative_tip_acceleration_m_s2": worst_pose_a_tip,
            "head_yaw_com_offset_from_axis_mm": yaw_radius,
            "head_pitch_carried_com_offset_from_axis_mm": pitch_offset,
            "head_roll_carried_com_offset_from_axis_mm": roll_offset,
            "printed_enclosure_yaw_inertia_about_drive_axis_kg_m2": (
                shell_props["yaw_inertia_about_ground_origin_g_mm2"]
                + printed_frame_props["yaw_inertia_about_ground_origin_g_mm2"]) / 1e9,
            "unweighed_harness_fastener_allowance_g": harness_mass,
            "allowance_assumed_x_mm": harness_x,
            "allowance_min_x_for_pose_screen_mm": harness_min_x,
            "allowance_if_at_x_minus20_a_tip_m_s2": harness_rear_a_tip,
        },
        "axes": {
            "head_yaw_datum_mm": M.HEAD_YAW_DATUM,
            "head_sweep_floor_z_mm": M.HEAD_SWEEP_FLOOR_Z,
            "head_sweep_to_shell_clearance_mm": M.HEAD_SWEEP_FLOOR_Z - M.BODY_Z_TOP,
            "yaw_shell_clashes_mm3": yaw_shell_clashes,
        },
        "envelope": {
            "shell_x_mm": (min(s[1] for s in M.SHELL_STATIONS), max(s[2] for s in M.SHELL_STATIONS)),
            "shell_width_max_mm": 2 * max(s[3] for s in M.SHELL_STATIONS),
            "shell_z_mm": (M.BODY_Z_BOTTOM, M.BODY_Z_TOP),
        },
        "checks": checks,
        "ok": all(checks.values()),
    }
    out = HERE / "generated" / "body-layout-checks.json"
    out.parent.mkdir(exist_ok=True)
    out.write_text(json.dumps(payload, indent=2) + "\n")
    print(json.dumps({"ok": payload["ok"], "checks": checks,
                      "whole_robot": payload["whole_robot"],
                      "shell_mass_g": shell_props["mass_g"],
                      "frame_mass_g": frame_props["mass_g"]}, indent=2))
    if not payload["ok"]:
        raise SystemExit(1)


if __name__ == "__main__":
    main()

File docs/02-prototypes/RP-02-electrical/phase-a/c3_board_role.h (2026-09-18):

/* CA-14 C3 board-role header — generated from RP-03 pin map v0.1
 * Source: docs/02-prototypes/RP-03-locomotion/base-control-architecture.md §3
 * Registration: RP03-P4-REG-02 / RP02-P4-REG-02 (2026-09-18)
 *
 * This is the C3 half of the CA-14 config source. It is not a carrier freeze,
 * not a SKU freeze, and not a byte-layout freeze. Soft BASE_LIMITS_SET values
 * may only tighten the compiled maxima below. A hash mismatch blocks arm.
 *
 * Carrier PCB still waits on a frozen map. N8R8 is not a silent substitute.
 */
#ifndef MAKAD_C3_BOARD_ROLE_H
#define MAKAD_C3_BOARD_ROLE_H

#define MAKAD_C3_BOARD_ROLE_REV        1u
#define MAKAD_C3_PINMAP_VERSION        0x0001u
#define MAKAD_C3_BOARD_ID              "ESP32-S3-DevKitC-1-N8"

/* Config identity. Replace the hash at freeze; a mismatch blocks BASE_ENABLE. */
#define MAKAD_C3_CONFIG_SOURCE         "rp03-pinmap-v0.1"
#define MAKAD_C3_CONFIG_HASH_PLACEHOLDER  0x00000000u

/* --- compiled hard maxima (conservative defaults until measured CoM) --- */
/* physics.md RANGE, not the 1.98 m/s² placement target. BC-09. */
#define MAKAD_C3_A_MAX_MM_S2           800     /* 0.80 m/s² */
#define MAKAD_C3_V_FOLLOW_MAX_MM_S     500     /* CON-19; cannot be weakened */
#define MAKAD_C3_V_CLAMP_MM_S          700     /* BD-06 cannot-exceed test limit */
#define MAKAD_C3_W_MAX_MRAD_S          3840    /* 220 °/s = 3.840 rad/s */
#define MAKAD_C3_V_CAL_MM_S            60      /* BM-11 / CC-12C clamp */
#define MAKAD_C3_CMD_TTL_CRUISE_MS     200     /* candidate, unregistered */
#define MAKAD_C3_CMD_TTL_ONESHOT_EXTRA_MS 250  /* plus duration_ms; unregistered */
#define MAKAD_C3_HEARTBEAT_TIMEOUT_MS  150     /* candidate, unregistered */
#define MAKAD_C3_QUEUE_DEPTH           2       /* candidate, unregistered */
#define MAKAD_C3_CC12C_ARM_TTL_MS      5000    /* candidate, unregistered */
#define MAKAD_C3_GEARBOX_TSTOP_C       85      /* stop-on-temperature candidate */

/* --- pin map v0.1: ESP32-S3-DevKitC-1-N8 --- */
/* Strapping GPIO0/45/46: unassigned, no safety OUTPUTS.
 * GPIO3: ESTOP_N input-only exception. GPIO19/20 USB. GPIO43/44 USB-UART.
 * GPIO48: WDI (RGB LED released). Spare safe GPIO: 2, 10, 38 (≥2 required). */

#define MAKAD_C3_GPIO_ENC_L_A          4
#define MAKAD_C3_GPIO_ENC_L_B          5
#define MAKAD_C3_GPIO_ENC_R_A          6
#define MAKAD_C3_GPIO_ENC_R_B          7
#define MAKAD_C3_GPIO_PWM_L            11
#define MAKAD_C3_GPIO_PWM_R            12
#define MAKAD_C3_GPIO_DIR_L            13
#define MAKAD_C3_GPIO_DIR_R            14
#define MAKAD_C3_GPIO_nSLEEP           21  /* fail-safe pull-down to inhibit */
#define MAKAD_C3_GPIO_nFAULT           9
#define MAKAD_C3_GPIO_CLIFF_FL         15
#define MAKAD_C3_GPIO_CLIFF_FR         16
#define MAKAD_C3_GPIO_CLIFF_REAR       8
#define MAKAD_C3_GPIO_OBST_IR          1   /* ADC1; not ToF */
#define MAKAD_C3_GPIO_BUMP             47
#define MAKAD_C3_GPIO_ESTOP_N          3   /* input only; strapping exception */
#define MAKAD_C3_GPIO_ENERGY_OK        39
#define MAKAD_C3_GPIO_MOTOR_PRESENT    40
#define MAKAD_C3_GPIO_IMU_MOSI         35
#define MAKAD_C3_GPIO_IMU_MISO         36
#define MAKAD_C3_GPIO_IMU_SCLK         37
#define MAKAD_C3_GPIO_IMU_CS           41
#define MAKAD_C3_GPIO_IMU_INT          42
#define MAKAD_C3_GPIO_UART1_TX         17
#define MAKAD_C3_GPIO_UART1_RX         18
#define MAKAD_C3_GPIO_WDI              48

#define MAKAD_C3_GPIO_SPARE_0          2
#define MAKAD_C3_GPIO_SPARE_1          10
#define MAKAD_C3_GPIO_SPARE_2          38
#define MAKAD_C3_SPARE_SAFE_COUNT      3

/* ISENSE / IPROPI is not on the MCU in v0.1. A later landing consumes a named
 * spare through change control and re-proves SPARE_SAFE_COUNT >= 2. */

#define MAKAD_C3_GPIO_STRAPPING_UNUSED_0   0
#define MAKAD_C3_GPIO_STRAPPING_UNUSED_45  45
#define MAKAD_C3_GPIO_STRAPPING_UNUSED_46  46

#if (MAKAD_C3_SPARE_SAFE_COUNT) < 2
#error "CA-14 / RP03-P08: C3 pin map must retain >= 2 unassigned safe GPIO"
#endif

#endif /* MAKAD_C3_BOARD_ROLE_H */

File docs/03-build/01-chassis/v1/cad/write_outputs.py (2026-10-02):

"""Write generated dimensional, frame, and mass-property reports."""

from __future__ import annotations

import json
from pathlib import Path

import body_chassis_model as M


HERE = Path(__file__).resolve().parent
OUT = HERE / "generated"


def write_json(name, payload):
    OUT.mkdir(parents=True, exist_ok=True)
    (OUT / name).write_text(json.dumps(payload, indent=2) + "\n")


def main():
    dims = {
        "layout_id": M.LAYOUT_ID,
        "layout_revision": M.LAYOUT_REV,
        "units": "mm",
        "coordinate_convention": "+X forward, +Y robot-left, +Z up; origin at axle ground-contact line",
        "wheel_track_mm": M.TRACK,
        "wheel_od_mm": M.WHEEL_OD,
        "wheel_width_mm": M.WHEEL_WIDTH,
        "axle_height_mm": M.AXLE_Z,
        "front_ball_contact_mm": list(M.BALL_CONTACT),
        "axle_stack": {
        "decision": "03-build D-007 axle architecture with D-012 bearing selection (axle-stack.md); geometry basis RP03-CAD-05",
            "motor_face_y_mm": M.MOTOR_FACE_Y,
            "motor_plate_y_mm": list(M.AXLE_FLANGE_Y),
            "bearing_housing_y_mm": list(M.AXLE_HOUSING_Y),
            "bearing_housing_radius_mm": M.AXLE_HOUSING_RADIUS,
            "retaining_cap_y_mm": list(M.AXLE_CAP_Y),
            "bearing_model": M.BEARING_MODEL,
            "bearing_centre_y_mm": list(M.BEARING_Y),
            "set_screw_y_mm": M.SET_SCREW_Y,
            "stub_shaft_radius_mm": M.STUB_SHAFT_RADIUS,
            "stub_shaft_y_mm": list(M.STUB_SHAFT_Y),
            "stub_flange_radius_y_mm": list(M.STUB_FLANGE),
            "stub_spigot_radius_y_mm": list(M.STUB_SPIGOT),
            "wheel_pocket_radius_mm": M.WHEEL_POCKET_RADIUS,
            "wheel_pocket_floor_y_mm": M.WHEEL_POCKET_FLOOR_Y,
            "cheek_abs_x_mm": list(M.AXLE_CHEEK_X),
            "motor_relief_half_x_mm": M.MOTOR_RELIEF_HALF_X,
            "wheel_running_clearance_min_mm": M.WHEEL_RUNNING_CLEARANCE_MIN,
            "axle_crossmember": "removed; coaxial motors fill the axle line",
        },
        "body_shift_x_mm": M.BODY_SHIFT_X,
        "body_axis_x_mm": M.BODY_AXIS_X,
        "battery_center_mm": list(M.BATTERY_CENTER),
        "battery_size_mm": list(M.BATTERY_SIZE),
        "battery_mount": "chassis tub under the deck, flush with the deck top; removable bottom hatch through a shell-floor opening",
        "ball_mount_mode": M.BALL_MOUNT_MODE,
        "ball_mount": "vendor flange top face seats on the printed pod at Z 29; three M3 from inside the pod pocket; pod tied to the front crossmember of CHASSIS_FRAME_FRONT_MODULE by two M3 into heat-set inserts",
        "ball_screw_points_mm": [list(point) for point in M.ball_screw_points()],
        "ball_pod_x_mm": list(M.BALL_POD_X),
        "ball_pod_half_width_mm": M.BALL_POD_HALF_WIDTH,
        "touch_cap_face_x_mm": M.TACTILE_NOSE_FACE_X,
        "touch_cap_half_width_mm": M.TACTILE_CAP_HALF_WIDTH,
        "touch_cap_z_mm": list(M.TACTILE_CAP_Z),
        "touch_cap_travel_mm": M.TACTILE_NOSE_TRAVEL,
        "front_range_sensor_face_mm": [M.FRONT_RANGE_SENSOR_FACE_X, M.FRONT_RANGE_SENSOR_Y, M.FRONT_RANGE_SENSOR_Z],
        "front_range_face_ahead_of_ball_contact_mm": M.FRONT_RANGE_SENSOR_FACE_X - M.BALL_CONTACT[0],
        "front_range_required_from_ball_contact_mm": M.FRONT_RANGE_REQUIRED_MM,
        "front_range_rated_max_mm": M.FRONT_RANGE_MAX_MM,
        "body_shell_x_mm": [M.BODY_X_REAR, M.BODY_X_FRONT],
        "body_shell_z_mm": [M.BODY_Z_BOTTOM, M.BODY_Z_TOP],
        "body_visible_height_mm": M.BODY_Z_TOP - M.BODY_Z_BOTTOM,
        "body_width_lower_mm": M.BODY_WIDTH_LOWER,
        "body_width_upper_mm": M.BODY_WIDTH_UPPER,
        "shell_thickness_mm": M.SHELL_THICKNESS,
        "body_mount_points_mm": [list(point) for point in M.BODY_MOUNT_POINTS],
        "body_locating_points_mm": [list(point) for point in M.BODY_LOCATING_POINTS],
        "body_mount_fastener": "M4 through-bolt, four places",
        "panel_overlap_mm": M.PANEL_OVERLAP,
        "front_panel_width_bottom_top_mm": [M.FRONT_PANEL_BOTTOM_WIDTH, M.FRONT_PANEL_TOP_WIDTH],
        "rear_panel_width_bottom_top_mm": [M.REAR_PANEL_BOTTOM_WIDTH, M.REAR_PANEL_TOP_WIDTH],
        "panel_edge_intent": "front and rear panel side edges are parallel to their corresponding shell end-profile side edges",
        "front_panel_fasteners_mm": [list(point) for point in M.FRONT_PANEL_FASTENERS],
        "rear_panel_fasteners_mm": [list(point) for point in M.REAR_PANEL_FASTENERS],
        "speaker_center_mm": list(M.SPEAKER_CENTER),
        "speaker_basket_diameter_mm": M.SPEAKER_BASKET_DIAMETER,
        "speaker_cone_diameter_mm": M.SPEAKER_CONE_DIAMETER,
        "microphone_ports": [list(port) for port in M.MICROPHONE_PORTS],
        "audio_status": "provisional requirement envelopes pending RP-05/RP-06 part selection",
        "head_yaw_datum_mm": list(M.HEAD_YAW_DATUM),
        "head_origin_in_chassis_mm": list(M.HEAD_ORIGIN_IN_CHASSIS),
        "head_local_yaw_mm": list(M.HEAD_LOCAL_YAW),
        "neck_allocation_mm": M.NECK_ALLOCATION,
        "neutral_overall_physical_height_mm": M.OVERALL_PHYSICAL_HEIGHT,
        "overall_height_status": f"{M.OVERALL_PHYSICAL_HEIGHT:.0f} mm neutral stack (Layout 04 head, 49.5 mm neck to the body top; was 304 mm)",
        "head_motion_envelope": "RP-01 Layout 04 motion-envelope.json: usable roll ±18 / pitch −22…+40, hard stops roll ±21 / pitch −25…+43; stops alone keep ≥4 mm to the yaw disc (≥2 mm at 1° overtravel)",
        "yaw_drive": "XC330-M181 through a 1:1 spur pair",
        "yaw_disc_top_z_mm": M.YAW_DISC_TOP_Z,
        "pi_cooler_headroom_mm": M.PI_COOLER_HEADROOM,
        "head_sweep_floor_z_mm": M.HEAD_SWEEP_FLOOR_Z,
        "rp01_yoke_status": "live Layout 04 straight legs on a flush yaw turntable; body-side bearing, ring gear, pinion and servo are packaging envelopes; not load-rated or fabrication-final",
        "tcrt_channels": list(M.TCRT_CHANNELS),
        "tcrt_rear_center_mm": list(M.TCRT_REAR_CENTER),
        "tcrt_optical_face_z_mm": M.TCRT_OPTICAL_FACE_Z,
        "tcrt_guard_bottom_z_mm": M.TCRT_GUARD_BOTTOM_Z,
        "tcrt_rear_contact_lookahead_mm": M.TCRT_REAR_LOOKAHEAD,
        "tcrt_coverage_note": "CAD-context choice: rear-only cliff channel; no front or lateral cliff-safety claim",
        "rear_keel_color_alpha": [M.REAR_KEEL_COLOR, M.REAR_KEEL_ALPHA],
        "rear_keel_group": "REAR_SKID_TCRT_MODULE/REAR_SKID_TCRT_KEEL",
        "rear_keel_stations_mm": [list(station) for station in M.REAR_KEEL_STATIONS],
        "rear_keel_mount": "four M3 screws up into the rear crossmember underside of CHASSIS_FRAME_REAR_MODULE",
        "skid_pad_center_mm": list(M.SKID_PAD_CENTER),
    }
    write_json("dimensions.json", dims)
    write_json("frames.json", M.FRAMES)
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

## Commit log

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2026-09-13 docs: correct RP-01 proof boundary
    [layout03-paper-model.xlsx]
2026-09-14 docs: head component review and body-SBC suggestion (MEM-20260914-01)
    Review of the selected head parts (ESP32-S3-Zero C2, Waveshare
    ESP32-S3-LCD-4.3 face, Camera Module 3 Wide). No lock reopened.
    Recorded as suggestions, not decisions:
    - Raspberry Pi 5 2 GB as the suggested SBC lead candidate at current
    India prices after the 2026 DRAM rises; Pi 4 now cost-dominated
    - IMX708 support binds the SBC to Raspberry Pi in practice
    - display refresh expectation 30-40 fps; suggest registering the gate
    at >=30 fps sustained
    - four PDM mics need a front end on a Pi-class SBC
    - C2-relay display link recorded as an alternative under consideration
    - C2 flashing note corrected (USB-Serial-JTAG, no BO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
2026-09-18 docs: select the ball transfer as V1 front support
    Record BD-08 in SCOPE-09 and the dimensional baseline so the chassis is designed around a no-trail front contact. Keep the caster as the comparison swap; do not close ADR-04 or authorize purchase.
2026-09-19 docs: record RP-03 CAD envelopes and print-vs-buy in one research file
    Paper pass named the axle-vs-ball height gap, the missing Ø84×21 SKU, and the absent India D02 encoder suffix without freezing a buy; adapters print, scored articles do not.
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2026-09-23 cad(rp-06): add RP-01 head Layout 04
    Head layout 04 replaces the Layout 03 spindle with a yaw turntable disc
    and a 40 mm neck. It publishes axes.json, motion-envelope.json and
    mass-placement.json so the body/chassis assembly can read the yaw datum,
    A0, disc size and yaw-carried mass instead of hard-coding them.
2026-09-23 cad(rp-06): remove mobility belt and rework body service panels
    - Drop the lower mobility belt fascia, its M3 tabs and frame brackets;
    the shell's own lower band is now the outer surface.
    - Shell openings are the panel outline offset inward by a constant 2 mm
    land; panel straight side edges stay parallel to the shell end profile.
    - Replace the overlap frames and loose bosses with one internal frame per
    panel carrying four fused M3 bosses, with screw centres >= 7 mm inside
    the outline.
    - Raise the front panel to Z 58 so it lifts off forward over the chassis
    deck and crossmember; stop the deck inside the front wall and pass the
    rails through open-bottom shell notches.
    - Move the GP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
    [body_chassis_model.py, write_outputs.py]
2026-09-23 cad(rp-06): move rear skid/TCRT into a keel; park the stinger tail
    - Replace the eleven-station translucent rear tail with a compact faceted
    keel bolted under REAR_SKID_CROSSMEMBER by four M3 screws. It carries
    the replaceable wear shoe (X -43, 3.5 mm clearance), the guard lips
    (7 mm) and the TCRT cartridge (X -70, 10 mm optical face, 27 mm
    lookahead); the crossmember and shell floor pass the cable riser.
    - Shrink the anti-tip wear shoe from 22x16 to 12x10 mm and slim the keel
    nose around it (knife edge X -28 -> -33); move the forward keel screws
    to X -52.5 so their counterbores clear the shoe. Keel body 17.8 -> 15.4
    cm3.
    - Make the keel translucent ivory (alpha 0.34) so the ca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
    [body_chassis_model.py, write_outputs.py]
2026-09-23 cad(rp-06): integrate head Layout 04 turntable yaw stage
    - Compose RP-01 head Layout 04 and read its yaw datum, A0, motion
    envelope, disc size and yaw-carried mass from the head's generated
    JSON instead of hard-coded Layout 03 values.
    - Drop the neck cowl and yaw-moving yoke shrouds. The body now carries
    the stationary yaw stage: thin-section bearing and clock-spring cable
    reserve above a 69 mm adapter plate, and an off-axis pinion with an
    XC330-size servo on +Y. The ring gear and its skirt move with the head
    up to the proud disc; a 90 mm shell opening passes the skirt.
    - Keep 10.5 mm of air above the Pi 5 cooler; shorten the head load posts
    and harness riser to the new plate h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
    [body_chassis_model.py, write_outputs.py]
2026-09-23 cad(rp-06): update layout checks for panels, rear keel and yaw stage
    - Service panels are measured from the built solids: 2 mm land, side-edge
    parallelism, fastener inset, single-solid frames with fused bosses, the
    GP2Y window, the front panel's lift-off path, and zero interference
    with the shell, chassis, frame, electronics, audio and sensors.
    - Rear keel: crossmember seat without interference, four M3, shoe fully
    backed (probe grid follows the shoe size), guards seated, TCRT clears
    the keel, tip-back contact order shoe -> guards -> keel/sensor, and the
    keel is translucent ivory.
    - Parked stinger tail: checked standalone (telescoping sleeves, rising
    sweep, blunt tip, inside th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
2026-09-23 cad(rp-06): regenerate layout-02 reports and snapshots for the panel rework
    Rebuilt from 39fdbfe in a clean worktree, so the outputs match committed
    source only.
    - checks: all 11 service-panel checks pass on measured geometry (2 mm
    land, parallel side edges, fastener inset, one-piece frames with fused
    bosses, GP2Y window, front-panel lift-off path, no panel-area clashes).
    - mass: BODY_SHELL_AND_PANELS 315 g; total 2611.6 g, CoM (9.10, 0.61,
    106.73) mm.
    - snapshots: the ten review views now show the raised front panel, the
    sensor window and the internal frames.
    74 of 77 checks pass. The three failures are head/neck checks, not
    panel ones: head Layout 04 as committed sits at a 49.5 m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
2026-09-23 cad(rp-06): head Layout 04 hard stops 3 deg past usable travel, 49.5 mm neck
    Fixes two RP-01 conflicts found after the turntable yaw stage landed.
    - hard stops now sit 3 deg beyond storyboard usable travel (roll +/-21,
    pitch -25/+43); stop-slot ends follow one shared definition in
    motion_envelope.py. With the stops alone, the head keeps 4.3 mm to the
    disc top (3.1 mm at a further 1 deg of overtravel), so no firmware
    roll/pitch limit is needed.
    - disc top Z-34.5, 15 mm proud of the body top, so the neck is 49.5 mm
    and the yaw-stage stack keeps 10.5 mm over the Pi 5 cooler.
    - yaw disc r62.5; legs set back 1.5 mm; roll-retainer slot widened to the
    new stop; C2 castellated exit reli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
2026-09-23 cad(rp-06): body yaw stage with 1:1 spur drive on head Layout 04
    Matches the body to head Layout 04 (49.5 mm neck, 293.5 mm stack).
    - yaw drive: off-axis XC330-M181 through a 1:1 spur pair (pitch 37 mm)
    and a coupling shaft. Replaces the 4.875:1 ring gear, which no XC330
    could run at the 63 rpm peak yaw; the M181 gives 129 / 95 rpm no-load at
    5.0 / 3.7 V.
    - head load path: the adapter plate now spans the upper-frame cross-members,
    which drop 2 mm; the two head load posts are removed.
    - everything in the yaw stage, stationary or turning, starts 10.5 mm above
    the Pi 5 cooler; shell opening is 45 mm radius.
    - checks: 1:1 spur mesh, servo speed margin at 3.7 V (1.3x), cooler
    headroo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
    [body_chassis_model.py, write_outputs.py]
2026-09-23 docs(rp-01): record head Layout 04 neck, stops, masses and yaw drive
    RP-01 still described the Layout 03 architecture (60 mm neck, ~509 g yaw,
    external yaw loop, stops at usable travel, M288 yaw candidate).
    - intent, physics, gates, decision D-08, concept note: 49.5 mm neck, best-case
    hard stops 3 deg past usable travel (pitch -25/+43, roll +/-21), nominal
    ~358/432/557 g roll/pitch/yaw (~547-572 g across the C2 range).
    - concept note: hollow through-bore cable route with a body-side clock spring
    replaces the external yaw loop; yaw servo is off-axis via a 1:1 spur pair.
    - material-finish-mass-decision: M012 is the 73 g turntable disc.
    - actuator-screen-01: XC330-M181-T is the yaw candi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
2026-09-23 docs(rp-06): record RP03-CAD-04 to -06 and the new CoM
    - decisions.md: RP03-CAD-04 ball pod, RP03-CAD-05 axle stack and
    RP03-CAD-06 body shift/battery tub, plus the skid amendment (X -27).
    - Layout 02 README and brief: axle stack, body placement, battery tub,
    new datums, measured running gaps, the legacy-runtime build steps, and
    the older body-side clashes the all-group sweep found.
    - Plan, checklist, TODO, RP-06 README and openitems: CoM now +20.2/103.7 mm
    (a_tip 1.91 m/s2), still short of +25/124; new open rows for the axle
    stack on real parts, body-side clashes, battery service path, mass
    register, and RP-03 docs held under the propagation hold.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
2026-09-23 cad(rp-06): layout-02 viewer pose controls for head and wheels
    Generate body-chassis.params.js from write_viewer_params.py: head
    roll/pitch/yaw over Layout 04 usable travel with parts bucketed into the
    head's R/P/Y frames (yoke legs, turntable spur and clamp ring ride yaw;
    the 1:1 pinion counter-rotates), and left/right wheel angles that drive
    the robot as a differential drive on the floor.
    All pivots are recomputed in chassis coordinates. The old head-yaw pivot
    was in head-local coordinates, 54 mm off the real yaw axis.
    check_viewer.mjs exercises the viewer's own resolver and transform code:
    fixed axes, no-slip spur mesh and wheel contacts, finite slider extremes.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
    [write_viewer_params.py]
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2026-09-24 docs(rp-02): record the 2S1P 18650 battery working selection
    Builder direction 2026-09-24: 2S closed, Li-ion NMC 18650, chosen on price
    and fit in the CAD tub. Working pack is two Samsung INR18650-25R cells with a
    2S 20 A balanced BMS (about 18 Wh, 110 g E). Recorded as unregistered and
    unpurchased.
    - decision.md, power-architecture.md (PA-03), electrical-design-basis.md,
    intent.md: chemistry and 2S rows marked as working selection
    - power-calculation-ledger.md 5.3: energy is about 2x the MD-01 requirement;
    near-empty sag at the historical 11.7 A peak is estimated at 5.4-5.7 V,
    below the 6.0 V low line (E, unmeasured)
    - power-component-candidate-screen.md 9.2: cell/BMS candidates, pri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
2026-09-24 cad(rp-06): 2S1P 18650 battery pack, resized tub and ballast bar
    RP03-CAD-07: replace the 48x75x24 mm, 280 g battery placeholder with the
    RP-02 working pack: two Samsung 25R cells (axes along Y) with a 2S 20 A BMS on
    top, 37.6x67x23.8 mm, 110 g E. The tub is derived from the pack (1.5 mm gaps,
    front wall unchanged, rear wall forward, half-width 36.5); the deck cut-out
    and shell floor opening follow. Chassis row -1.2 g, shell row +2.6 g.
    RP03-CAD-08: the lighter pack moved the register CoM from +20.2 to +18.8 mm,
    under the physics.md 2.5 +20 mm line. Add an 81.6 g mild-steel bar under the
    deck between the tub and the front crossmember, on two M3 screws from the deck
    top. CoM +20.6 / 105.8 mm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
    [body_chassis_model.py]
2026-09-25 cad(rp-06): power and safety boards, E-stop and pack interface in layout-02
    RP03-CAD-09: replace the single 121.5 g CONTROL_POWER_SENSORS row with real
    volumes and mass rows from the RP-02 board-specs.md v0.16 working direction:
    PCB-02 charge and system power (vertical on the rear-panel frame), PCB-03
    motor gate and head rail (above the battery tub), PCB-04 branch converters
    (under the compute tray), the SBS Mini and ATOF fuse holder pack interface,
    and the IDEC XW1E E-stop with its keep-out clear of the Pi cooler. PCB-01
    replaces the generic BMS on the pack (113.7 g). All board sizes and masses
    are estimates from unlaid-out part inventories; none is bench-proved or
    registered.
    CoM baseline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
    [body_chassis_model.py]
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2026-09-25 cad(rp-06): recessed IDEC XA rear E-stop in an octagonal well
    Replace the Ø40 XW1E puck on the rear panel with the IDEC
    XA1E-BV3U02KT-R (Ø29 mushroom, 2NC, 14 g, 23.9 mm deep). The switch
    sits on the floor of a tapered octagonal well printed with the rear
    panel, so the mushroom stands 12.6 mm proud instead of 20 mm, and an
    amber octagonal bezel serves as the ISO 13850 yellow background.
    - well clears the panel frame by 0.27 mm; keep-out clears PCB-02 and
    the Pi; centre moves to Z 105.5
    - mass register: E-stop row 40 g E -> 14 g D; CoM x +18.73 -> +19.41
    - checks: 108/109; the parked tail's root flange now lands on the
    well (rear_tail_clears_shell_and_panels), left failing on purpose
    -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
    [body_chassis_model.py]
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2026-09-29 build(chassis-v1): add 03-build folder; close ball-transfer nose in CAD (D-011, D-013)
    First commit of docs/03-build (governs from 2026-09-28): ledger D-001..D-013,
    project BOM, chassis v1 spec/checklist/joint register, axle stack, wheel and
    chassis-v1 CAD.
    Ball-transfer nose (J07/J08):
    - caster screwed from below (ISO 7380 M3 x 8) into CNC Kitchen M3 x 5.7
    inserts in a 6 mm pod seat; insert bores now interfere
    - constant-section nose so the cap slides the full 3 mm; snap-finger cap
    replaces the 0.5 mm flexures; pod sliver and an open chamfer slit fixed
    - lid: rear tongue under the shell band plus one M2 x 8 front screw
    - J10-8 cable slot and route via a new O5 crossmember/deck bore
    - c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
    [BOM.csv, frame-split.step, wheel-pair.step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]
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2026-10-01 build(chassis-v1): clear battery tub interface overlaps (D-028)
    - Size the shell floor opening to the hatch outline plus 0.5 mm, clearing
    the hatch flange and the tub screw bosses.
    - Move the front hatch bosses onto the tub front wall, between the ballast
    bar and the fuse holder; cut all bosses to Z 39.5 and lift the pack
    disconnect, its window and slide path to Z 40-50.
    - Record the IMU M2 screws in the deck as an accepted overlap, guarded on
    their expected volume.
    - Update the shell and frame mass rows from measured volumes.
    - Make check_layout.py complete under OCC 7.9.3: leaf-aware box prefilter,
    skip discarded C3 compound booleans, pick the front deck for the IMU row.
    116/11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
    [chassis-v1.step]
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2026-10-01 build(chassis-v1): clear driver, nose-lid and screw-sweep check failures (D-029, D-031)
    - Turn the #3297 driver boards long side along Y at X 38.5-56.3 so they
    clear the PCB-03 edge plugs and the body doglegs; move the J15B posts to
    X 41.05, behind the body M4 feet; re-place the inline motor pairs and
    the motor-lead harness branch.
    - Lower the GP2Y lead reserve to 2 mm so the lid hump clears the front
    panel's lift-off path.
    - Model the motor face-screw heads as ISO 7380 domes; the set-screw sweep
    clears again.
    - check_layout.py: read the IMU deck top from DECK_Z.
    - Full check_layout.py: 119/119 pass. STEPs rebuilt.
    [chassis-v1.step]
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2026-10-01 build(chassis-v1): inline main-fuse holder on a deck bracket; close review doc items (D-032)
    - No ATO fuse fits the +Y channel; CH-028 becomes a Littelfuse 0FHA0001ZXJ
    inline holder above the channel on a printed front-deck bracket,
    source-adjacent per PA-02. Frame mass +0.8 g.
    - check_layout.py: holder-on-shelf contact counts as mounted.
    - Docs: checklist status and rotating-clearance text, BOM release
    blocker 6, J15B status row; gitignore check progress files.
    - Checks: check_layout 119/119, wheel on chassis 6/6, frame fasteners 9/9,
    battery/ballast all pass. chassis-v1.step built from committed sources
    plus this change only (a parallel session's uncommitted wheel edits are
    exc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
    [BOM.csv, chassis-v1.step]
2026-10-02 build(chassis-v1): print each frame end as one module; one-screw hub caps (D-033)
    Implements the fastener review (research/fastener-review.md):
    - Front and rear frame modules: deck, both rails and crossmember are one
    print per end. J05/J06 tongue joints and J16 deck screws are removed
    (10 M3 screws, 10 inserts; CH-073-075 retired, CH-077 14 -> 4). This also
    fixes the rear deck's detached J16 pads. Frame prints go from 11 to 5.
    - Hub cap: one central ISO 7380 M3 x 10 into a tapped stub end, with two
    clocking pegs, replaces 6 x M2 x 6 per wheel (CH-059 12 -> 2).
    - Mass register: frame 219.1 g, axle 50.4 g, total 2615.1 g.
    - Checks: frame fasteners 9/9, nose 12/12, keel 21/21, battery/b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
    [BOM.csv, chassis-v1.step, frame-split.step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]
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2026-10-03 build(pcbs): add 04-pcbs board register and power-board build deltas (D-038)
    - New docs/03-build/04-pcbs/: README board register (PCB-01..PCB-12,
    CH-064) and power-boards.md, the build deltas to the read-only RP-02
    board-specs (bought TIFPS0629, DRV8833 drivers, MOT3001 motor).
    Replaces the former 04-custom-pcb/ folder; 03-build README relinked.
    - D-038 same-day update: SMBJ8.5A leakage closed; drive-feed monitors
    become one INA2181A2 with a REF3312 1.25 V reference (CH-042).
    - C3 carrier J10-5/J10-6 labels carry the DRV8833 SLP/IN1/IN2/FLT
    mapping in both body and chassis models (strings only, no geometry).
    [BOM.csv]
2026-10-03 build(harness): wire list, pinouts and service breaks; split pack feed at the fuse (D-039)
    - New docs/03-build/05-harness/README.md replaces the RP-06 connector
    schedule for the build: full W01-W39 wire list, every pinout, J-PK
    isolator mating rule, crimp-tool policy, body/pack/head service breaks,
    drop and mass estimates.
    - Builder choice: fused feed forks at butt splices beside the fuse to
    PCB-03 J3-1 and PCB-02 J2-1; W04 and J2-2 deleted; negative splice is
    the power star (pack-to-gate 44 -> 25 mOhm typical).
    - Pack NTC break is a JST SM 2p in the +Y channel; J3-4 and J8-1 move to
    Micro-Fit 3.0 AWG22; Micro-Fit+ leads use UL1061 thin-wall wire.
    - Chassis CAD: NTC break and sta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
    [BOM.csv]
2026-10-03 build(pcbs): charge inlet PCB-13 and closed PCB-02 charge path (D-040)
    - New docs/03-build/04-pcbs/charge-path.md: the circuit from the USB-C
    adapter to the pack entry. Covers PCB-13 (GCT USB4140, TVS2200,
    ESDA25W, STUSB4500, STL6P3LLH6 input switch) and the PCB-02 BQ25798
    block, with values, ratings, the NVM image, the fault table and bench
    tests CP-01 to CP-14.
    - Datasheet corrections to RP-02:
    - TS divider 8.45k/324k keeps charging inside 0-50 C (was -3.5 to
    62 C);
    - D+ tied to D-;
    - BATP 100 Ohm Kelvin sense;
    - the VBUS side rated for the 20 V a blank STUSB4500 requests;
    - both NTC leads to PCB-02.
    - Inlet moves off PCB-02 onto a pad printed on the rear panel. The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
    [BOM.csv]
2026-10-03 build(body-v1): rear mushroom becomes the power button, no E-stop (D-041); exposed front speaker panel
    D-041 (power button):
    - The robot has no E-stop. The rear red mushroom is the momentary power
    button on the LTC2954 PB input: PCB-02 J2-9 (GH2, +Y edge) with a 10k
    wetting pull-up. INT also resets SYSTEM_ARM, so a press stops the drive
    and head in hardware. Hold 1 s to shut down; hold about 5 s to force off.
    - The latching NC IDEC XA1E (CH-046, superseded) is replaced by a 16 mm
    momentary 1NO mushroom (BO-018) in the same well envelope.
    - W22, J3-7 and the permit-chain E-stop term are removed (0 ohm link);
    W38 and J10-11 are not fitted. New W40 GH2 lead.
    - CAD: power_button_mushro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
    [BOM.csv, parts-list.xlsx]
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2026-10-07 build(head-v1): close fabrication-audit CAD blockers
    Wall thickness (all 27 printed parts screened at 20k samples; every part
    watertight, p05 >= 1.2 mm):
    - Pitch stop-pin lug leaves a 2 mm ligament; the pitch frame STL is now
    watertight.
    - Skin inset 1.3 mm (>= 1.2 normal on the rear taper) plus land doublers.
    - Front bezel band and crown offset 1.3 mm along their normals; window lip
    1.3 mm; glass 0.35 mm further back and narrowed to 106 mm; front chamfer
    9.5 mm; crown CSI opening follows the cavity.
    - Camera bracket, crown receivers, C2 tray jaws, servo strap and bearing
    retainers thickened or redesigned.
    Fasteners:
    - New check_fasteners.py samples every M2 shank (clearance, insert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
    [ears-v1.step, yaw-yoke.step]
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2026-10-07 build: Feetech actuator migration (D-046, D-047, D-048)
    Head pitch/roll move to the Feetech STS3045M (D-046) and body yaw to the
    Waveshare ST3215-HS on a 12 V yaw-only rail (D-047). D-048 integrates the
    yaw servo in the live body model.
    D-048 (body_v1_model.py):
    - ST3215-HS from the official Waveshare STEP, horn up on the D-044 pinion
    axis, case -X, 7.6 mm below the old XC330 seat so the horn-face plugs fit
    under the plate. The horn axis is 25.5 mm from the STEP origin (2D drawing),
    which the earlier check_feetech_yaw_* trial screens missed.
    - Frame-integral clamp ring with pillars on the corner-hole step, side walls
    to the pad, plug window open to -X; 4 x M2 x 8 mount screws (BO-06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
    [BOM.csv, sts3045m_reference.step, waveshare_feetech_st3215_hs_servo.step]
2026-10-07 fix(body-v1): correct ST3215-HS mount screw axes and tighten D-048 gates
    - Mount screws moved 0.8 mm to the real horn-face holes (X 7.7 / -16.75);
    the previous axes sat on solid case and the overlap had been waived as
    thread engagement. check_yaw_stage.py no longer waives case-mount screw
    overlaps and asserts the screw axes against the hole positions.
    - check_compute_mount.py gains a gate for the Pi USB-C plug reserve against
    the C3 DevKitC STEP; it currently fails (0.12 mm3): a low-profile plug must
    be selected and modelled, or the route changed.
    - Torque cap and case-top comments now say they are unverified assumptions.
    - D-048, the migration status and the D-048 report record th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
    [check_compute_mount.py]
2026-10-08 fix(body-v1): clear the Pi USB-C plug from the C3 DevKitC; shell fit on D-048
    - After the D-048 compute shift only 14 mm remain from the Pi edge to the
    C3 DevKitC face. HN-010 is now a right-angle USB-C whose cable exits down
    (-Z) into the existing pigtail drop, body <= 13 mm past the receptacle.
    PI_POWER_PLUG_RESERVE ends at Y -47.8: 1.74 mm to the DevKitC, 2.19 mm to
    the nearest C3 plug (J10-7). check_compute_mount.py ALL PASS.
    - BOM HN-010, harness README, D-048 and the migration status record the
    envelope; the bought plug must be measured against it.
    - check_shell_frame_fit.py on the D-048 layout: shell one solid, no frame,
    chassis, hardware, lowering, driver or wheel-arch cl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
    [BOM.csv]
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2026-10-09 build(head-v1): install STS3045M pitch and roll servos (D-049)
    Step 0 checked the STS3045M reference STEP against the Feetech drawing:
    axis and ear slots were right; the lead exit, slot necks and boss are
    corrected.
    Roll: goBILDA 4001-0025-0006 coupler drives a longer spindle, servo on an
    ear plate behind the torsion box, rear bearing 4.4 mm forward. Pitch:
    servo carried by the pitch frame (collar, web, floor), its 25T horn
    screwed to a widened +Y yoke leg. M2 ear joints with M2.5 washers. Rear
    trim on two off-axis seats. Yoke legs to be printed in CF filament.
    A0 re-solved (pitch axis 2.41 mm rearward); check_revision, fasteners,
    integration, envelope and the new D-049 audit pass; FEA pit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
    [BOM.csv, gobilda_4001-0025-0006.step, sts3045m_reference.step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]
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2026-10-10 build(head-v1): -Y pitch pivot and yoke-leg joints (D-051)
    The -Y pitch pivot was an Ø8 pin loose in Ø8.4 holes, 1.5 mm into the
    leg and unretained, and the yoke legs had no joint to the disc.
    - Pivot: MR106ZZ seated in the -Y leg pad on a 0.7 mm lip, a flush
    1.0 mm printed retainer on two M2 x 4, and a Ø6 D-shaft pin (11.5 mm)
    into a D-bore boss on the frame's -Y arm. Nothing stands proud of the
    leg face (the skin passes at 0.98 mm).
    - Legs: each plinth keys over a 11 x 4.5 x 6 mm block on the disc top
    and takes two M2 x 6 from its inner face into inserts in the key; the
    disc underside over the yaw pinion is untouched.
    - New check_d051_joints.py: PASS on the 7 x 8 grid, every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
    [BOM.csv, yaw-yoke.step]
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
